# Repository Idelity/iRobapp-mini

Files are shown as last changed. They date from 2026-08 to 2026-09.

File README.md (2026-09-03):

# iRobapp-mini
AI＋ロボット＋アプリケーションの三位一体で生まれる卓上マスコット「iRobapp」の軽量版プロトタイプ

## 📂 ディレクトリ構成 (Directory Structure)

```text
iRobapp-mini/
├── 📁 cad/                       # ハードウェア設計データ
│   ├── 📁 scripts/               # FreeCAD用のPython生成スクリプト
│   └── 📁 stl/                   # 3Dプリンター出力用のSTLファイル
├── 📁 docs/                      # プロジェクトの解説ドキュメント
│   ├── assembly-guide.md         # iRobapp-miniハードウェアの組み立て手順書
│   ├── component-dimensions.md   # iRobapp-miniパーツ寸法表（FreeCAD設計基準）
│   ├── concept.md                # iRobapp-miniのコンセプトガイドについては下記を参照
│   ├── contributing.md           # 開発者向け：ローカル環境構築 ＆ 開発開始手順書
│   ├── development-log.md        # iRobapp-mini 開発日記 
│   ├── pinout-wiring-table.md    # iRobapp-mini ピンアサイン・配線表
│   └── system-specifications.md  # iRobapp-mini ソフトウェア・システム機能仕様書
├── 📁 firmware/                  # XIAO ESP32-S3用のコード
│   ├── 📁 main/                  # メインの制御ファームウェア
│   └── 📁 eye_assets/            # GC9A01液晶に表示する目の画像・アニメーションデータ
├── 📁 iOSApp/                    # Xcode
│   └── 📁 iRobappMiniController/ # iPhoneアプリのコード
├── .agents                       # GitHub Copilot用のエージェント指示書
├── .gitignore                    # 不要なファイル（FreeCADのバックアップ等）を除外する設定
└── README.md                     # プロジェクトの全体説明書
```
## 📄 iRobapp Documentation

- 🇯🇵 Japanese Concept Guide（日本語版コンセプトガイド）  
  https://github.com/Idelity/iRobapp/blob/main/docs/iRobapp-concept.md

- 🌍 English Concept Guide  
  https://github.com/Idelity/iRobapp/blob/main/docs/iRobapp-concept-en.md

> [!💡 お知らせ / Notice]
> 本家プロジェクト **[iRobapp](https://github.com/Idelity/iRobapp)** は、こちらを参照してください。
> 並行稼働プロジェクト **[Mocapy（モカピー）](https://github.com/Idelity/Mocapy)** は、こちらを参照してください。
>

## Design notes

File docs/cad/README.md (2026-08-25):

# 🤖 iRobapp-mini 卓上マスコット：4大コア部品の設計解説

本プロジェクト（iRobapp-mini）のハードウェア骨格は、FreeCADスクリプトから自動生成される**「4つの独立したコンポーネント」**が密接に連携することで成り立っています。それぞれの役割と設計思想は以下の通りです。

## 1. 001_Head_Face_Connector（頭部フェイスマウント）
* **【役割】**：丸型液晶（WAVESHARE 1.28inch LCD Module (19192)）をガタつきなく前面にホールドし、視線アニメーションを表現する「顔」の筐体です。底面で首のサーボモーター（SG90）に繋がる関節パーツとダイレクトに接続します。
* **【主要な設計寸法（スペック）】**：
  * **外形サイズ**：直径 44.0 mm（半径 22.0 mm）、奥行き 20.0 mm の非常にコンパクトなコップ型の円柱ベース。
  * **液晶ポケット**：直径 38.0 mm（半径 19.0 mm）、深さ 4.0 mm（市場の一般的なGC9A01モジュールがクリアランス込みでぴったり収まるサイズ）。
  * **配線エスケープ**：中央に 16.0 mm × 16.0 mm の角型貫通穴を配置。液晶背面からのFPCケーブルやジャンパ線をそのまま首の下へと逃がせる設計。
  * **マウントインターフェース**：首ジョイント（002）と結合するための、ピッチ 27.5 mm のM2ネジ用貫通穴（直径 2.2 mm）を2箇所に配置。
* **【設計のこだわり・評価ポイント】**：
  * **「耳」を兼ねたマウント設計**：頭部ベース（円柱）の底面に、幅 8.0 mm × 長さ 36.0 mm のフラットな「耳（拡張ブロック）」を一体化させて結合（`fuse`）している点が非常にスマートです。これにより、コンパクトな丸型ヘッドのデザインを維持したまま、サーボ固定用のネジ穴ピッチ（27.5mm）を綺麗に確保できています。
  * **3Dプリントを意識したブーリアン（くり抜き）順序**：液晶用ポケット、配線穴、M2ネジ穴をすべて1つのリストにまとめ、一括で結合してからメインボディをくり抜く（`cut`）シンプルなトポロジーを採用。FreeCAD上のトポロジーエラーが起きにくく、コードの実行速度も速い美しいスクリプト構成です。

## 2. 002_Neck_Joint_Mount（首ジョイントマウント）
* **【役割】**：頭部（001）と本体（003）を物理的に接続し、マスコットに上下（チルト）と左右（パン）の2軸（2自由度）の動きを与えるための中間関節パーツです。SG90サーボモーターを2個、直角に配置できる構造をスクリプトで自動生成します。
* **【主要な設計寸法（スペック）】**：
  * **頭部接続インターフェース**：幅 8.0 mm × 長さ 36.0 mm の上部プレート。001番の頭部底面と完全に一致するピッチ 27.5 mm のM2ネジ用貫通穴（直径 2.2 mm）を2箇所に配置。
  * **サーボポケット**：幅 23.0 mm × 厚み 12.8 mm（SG90サーボ本体の規格寸法にクリアランスを持たせた落とし込み穴）。
  * **サーボ固定マウント**：SG90のフランジ（耳）をネジ留めするための、ピッチ 27.5 mm のM2ネジ穴をY軸方向に配置。
* **【設計のこだわり・評価ポイント】**：
  * **完全なパラメータ同期（100%の嵌合整合性）**：001番のスクリプトで定義されていた `servo_screw_pitch = 27.5` という寸法が、この002番でも `head_screw_pitch = 27.5` として完全に引き継がれています。これにより、3Dプリント出力後に「ネジ穴が合わない」というトラブルが理論上発生しない完璧な連携設計になっています。
  * **空間効率の高いT字ブロック構造**：上部プレート、垂直壁、底部プレートを段階的に `fuse`（結合）し、そこにサーボポケットとネジ穴を一括で `cut`（くり抜き）するシンプルなトポロジーを採用。3Dプリンターで出力する際にも強度が保たれやすい肉厚（3mm）が確保されています。

## 3. 003_Body_Base_Case（本体ボトムケース）
* **【役割】**：マスコット全体の「体重」を支えるデスクトップ土台であり、首を左右に振る（パン）ためのSG90サーボモーター、メインマイコン（XIAO ESP32-S3）、スピーカー、電源スイッチ、および安全のためのヒューズホルダーをすべて内包する統合型エンクロージャーです。
* **【主要な設計寸法（スペック）】**：
  * **外形サイズ**：底面直径 70.0 mm（半径 35.0 mm）、上面直径 56.0 mm、高さ 40.0 mm の安定感のあるコーン形状。
  * **内蔵スペース**：肉厚 3.0 mm を均一に維持した広大なインナーポケット（下部からアクセス）。
  * **天面サーボマウント**：首振り用SG90サーボを落とし込む 13.4 mm × 23.4 mm のスリットと、002番と連携するピッチ 27.5 mm のM2ネジ穴（Z軸垂直貫通）を配置。
  * **背面インターフェース**：幅 12.0 mm × 高さ 19.0 mm の小型ロッカースイッチ用角穴、直径 12.0 mm のパネルマウント型ヒューズホルダー用丸穴、および **XIAO ESP32-S3用の給電・通信用USB-Cポート窓（幅 11.0 mm × 高さ 6.5 mm）** をまとめて配置。
* **【設計のこだわり・評価ポイント】**：
  * **一箇所に集約された外部インターフェース**：スイッチ、ヒューズ、USB-Cポートという「外から触る・挿す」必要のある要素をすべて背面（Y軸マイナス方向）の壁面へ機能的に集約しました。ロボットの正面側からは配線が一切見えないため、デスクトップマスコットとしてのノイズのない美観を保てます。
  * **コーン（円錐台）形状による低重心化**：頭部に液晶やサーボなどの重量物が集中する卓上ロボットにおいて、土台の底面を広く（直径70mm）、上部を狭くする設計は、ロボットが動いたときのブレや転倒を物理的に防ぐ非常に理にかなったアプローチです。

## 4. 004_Bottom_Lid_Battery_Holder（底蓋兼バッテリーホルダー）
* **【役割】**：003番の本体ボトムケースの底面にカチッとはめ込む蓋パーツです。内蔵するリチウムイオンポリマー（LiPo）バッテリーを物理的に挟み込んで固定し、ケース内部で部品が動いたり暴れたりするのを防ぐ「ホルダー」の機能も兼ね備えています。
* **【主要な設計寸法（スペック）】**：
  * **外形サイズ**：直径 約 63.2 mm（半径 31.6 mm）、ベース厚み 2.0 mm の薄型円盤構造。003番の底面内径（64.0 mm）に対して、3Dプリンターでの出力収縮や嵌め合いを考慮した **片側 0.2 mm（全体で 0.4 mm）のクリアランス** をあらかじめ自動計算で適用。
  * **バッテリーホルダー部**：幅 26.0 mm、厚み 8.0 mm までの小型LiPoバッテリー（500mAh〜800mAhクラス）をぴったりホールドできる、長さ 30.0 mm × 厚み 2.0 mm の一対の垂直固定リブ（壁）を中央に配置。
* **【設計のこだわり・評価ポイント】**：
  * **3Dプリント一発出力に適した「積層構造」**：オーバーハング（空中に浮く部分）が一切ない設計になっており、3Dプリンターで出力する際に「サポート材」を全く必要としません。底面を下にして置くだけで非常に綺麗かつスピーディにプリントが可能です。
  * **メンテナンス性と安全性の両立**：バッテリーを両サイドから適度な摩擦で挟み込む「クリップ構造」にしているため、ネジ留めが不要です。バッテリーの交換や、内部の配線メンテナンスを行いたい時は、底蓋を外すだけで簡単にアクセスできる親切な設計になっています。

---

### 💡 設計思想の評価（パラメトリック・モジュール化）
FreeCAD上でパーツごとにスクリプトを分離したことで、**「頭（液晶表示・配線窓） ↔ 首（サーボ結合・M2ピッチ27.5mm） ↔ 体（サーボ格納・マイコン固定） ↔ 底蓋（バッテリー保持）」**という一連の物理的・機能的リンクが綺麗にカプセル化されています。
これにより、「液晶のサイズを変えたい時は001だけ」「サーボを別のものに変えたい時は002と003だけ」「バッテリーを大容量化したい時は004だけ」というように、他の部品に影響を与えずパラメトリックに独立してカスタマイズできる点が非常に優れた設計思想です。

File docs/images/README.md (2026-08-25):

# iRobapp-mini 画像・図面アセット管理

このフォルダには、`iRobapp-mini` の設計、回路、ドキュメントで使用する画像やデザインの元データを格納しています。

---

## 🔌 回路結線図の更新ルール 🎵

回路図（ピンアサインや配線）に変更があった場合は、以下の手順でデータを更新してください！
画像ファイル名（`.png`）とフリーボードから出力したファイル名（`.pdf`）は、常に同じ名称（`circuit-diagram`）で統一して管理しています。

### 🔄 更新の 3 ステップ

1. **Mac のフリーボードで修正する**
   * 同フォルダにある元データ `circuit-diagram.pdf` を Mac で開き、フリードーにpdfの内容を貼り付けてピンアサインや配線をパパッと修正します。
2. **画像（PNG）として書き出す**
   * 修正が終わったら、フリーボードから「PDFとして書き出し」→「PNG形式（ファイル名：`circuit-diagram.png`）」として Mac に保存します。
3. **GitHub へ上書きアップロード！**
   * GitHub のこのフォルダ（`docs/images/`）を開き、新しく作った `circuit-diagram.png` と `circuit-diagram.pdf` の両方を**同じファイル名のままドラッグ＆ドロップ**して上書きコミットします。

> 💡 **ここがポイント！**
> ファイル名が同じであれば、ドキュメント（`ピンアサイン・配線表.md`）側のリンクを書き直さなくても、自動的に最新のきれいな回路図にパッと切り替わります！

---

## 📂 ファイル一覧

| ファイル名 | 形式 | 役割 |
| :--- | :--- | :--- |
| **`circuit-diagram.png`** | 画像 (PNG) | 各種ドキュメント（Markdown）表示用の配線図 |
| **`circuit-diagram.pdf`** | Mac編集データ | 再編集・修正を行うためのフリーボード元データ（バックアップ） |

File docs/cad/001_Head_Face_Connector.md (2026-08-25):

## 1. 001_Head_Face_Connector（頭部フェイスマウント）

* **【役割】**：丸型液晶（Waveshare 1.28inch LCD Module）をガタつきなく前面にホールドして視線アニメーションを表現すると同時に、内部にオーディオアンプとスピーカーを格納する、iRobapp-miniの「顔と音」を司る中空筐体です。底面で首のサーボモーター（SG90）に繋がる関節パーツとダイレクトに接続します。

### 📐 主要な設計寸法（スペック）
* **外形サイズ**：直径 44.0 mm（半径 22.0 mm）、奥行き 20.0 mm の非常にコンパクトでクリーンな円柱ベース。
* **液晶ポケット**：直径 38.0 mm（半径 19.0 mm）、深さ 4.0 mm（WAVESHARE 1.28inch LCD Module (19192) がクリアランス込みでぴったり収まるサイズ）。
* **【新設】コネクタ逃げスリット**：液晶ポケットの下部（Y軸マイナス方向）に、基板裏の突起部品を逃がすための**幅 20.0 mm × 縦 5.0 mm × 深さ 4.0 mm のスクエアスリット**を配置。
* **配線エスケープ**：中央に **直径 22.0 mm（半径 11.0 mm）のクリーンな完全貫通丸穴（センターVoid）** を配置。液晶背面からの配線や各パーツのジャンパ線をそのまま首の下へと最短距離で逃がせる設計。
* **マウントインターフェース**：首ジョイント（002）と結合するための、ピッチ 27.5 mm のM2ネジ用穴（半径 1.1 mm / 深さ 5.0 mm の浅型仕様）を2箇所に配置。外形の円柱の厚み内に美しく内蔵。

### ⚙️ 設計のこだわり・評価ポイント
* **現物合わせによる「コネクタ逃げ」の精密設計**：
  秋葉原で調達した Waveshare 19192 の実物基板にある下部の出っ張りに合わせ、干渉を避ける専用の逃げスリット（`conn_escape`）を新設。これにより液晶が浮かずに100%奥までフラットにはめ込めるようになりました。
* **限られた空間への音響システムの高密度実装**：
  外径44mmという極小のヘッドサイズを維持したまま、内部のデッドスペース（床面左側および右側側面）を有効活用し、アンプ固定リブとWスピーカーリブをブーリアン演算で一体化。ガタつきのない強固な内装構造を実現しています。
* **3Dプリントを意識した高精度な一体化トポロジー**：
  すべてのくり抜き用カッター（液晶ポケット、コネクタスリット、センターVoid、ネジ穴）を1つのオブジェクトに結合して一発で `cut` した後、追加リブ群をダイレクトに `fuse` する美しいスクリプト構成を採用。FreeCAD上でのトポロジーエラーを完全に排除しています。

### 📺 内蔵部品リスト

頭部ユニットは「視覚（顔）」と「聴覚（音声出力）」の表現をワンパッケージに凝縮し、首パーツへの負担を減らすため効率的に肉抜きされた高密度構造をしています。

* **WAVESHARE 1.28inch LCD Module (19192) × 1個**
  * **【配置】**：頭部前面に設計されたフロントポケットに、下部コネクタをスリットに合わせる形でガタつきなく綺麗にはめ込まれます。
  * **【役割】**：マスコットの「顔（液晶画面）」となり、駆動チップ（GC9A01）を介してファームウェアから描画される豊かな表情やアニメーションを映し出します。
* **SparkFun I2S Audio Breakout (MAX98357A搭載) × 1個**
  * **【配置】**：頭部内部の左側奥の床面（floor_tの上）に新設された、**高さ 10.0 mm / 厚み 2.0 mm の専用アンプ挟み込みリブ（2基）**の間にカチッと固定されます。
  * **【役割】**：ESP32-S3から送られてくるデジタル音声データを高品質なアナログ音声信号に変換・増幅し、Gemma-2Bの声をリアルタイムに響かせる脳の役割を果たします。
* **ブレッドボード用ダイナミックスピーカー (MS128-12R) × 1個**
  * **【配置】**：頭部内部の右側側面に配置された、**幅 5.0 mm / 縦 15.0 mm の15mm幅ワイド削り切りWリブ**（Z=12.0mmとZ=4.5mmの2基）の溝にスライドしてホールドされます。
  * **【役割】**：I2Sアンプからの信号を受け、圧縮なしの音声ストリーミングデータをクリアな音圧で卓上に届けます。
* **液晶および音響用 配線ケーブル一式**
  * **【ルート】**：液晶・アンプ・スピーカーから伸びるすべてのジャンパ線は、中央の**直径 22.0 mm の完全貫通丸穴**をストンと通り抜け、外から一切見えない状態でそのまま首（002）の中空スペースへと引き込まれます。

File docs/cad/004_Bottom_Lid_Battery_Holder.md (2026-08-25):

 ## 4. 004_Bottom_Lid_Battery_Holder（底蓋兼バッテリーホルダー）

* **【役割】**：iRobapp-mini の最底面を閉じる蓋（リッド）であり、同時に電源系の生命線である「リチウムイオンポリマー電池」「保護ヒューズ」「電源メインスイッチ」をワンパッケージで確実にホールドする電源マネジメントベースです。

### 📐 主要な設計寸法（スペック）
* **全体サイズ**：直径 約63.2 mm（半径 31.6 mm / 本体底面 70.0 mm に対し、壁厚 3.0 mm とクリアランス 0.4 mm を引いたジャストサイズ）。厚み 2.0 mm の円盤ベース。
* **バッテリーホルダー仕様**：
  * 千石電商で調達したリポ電池（DTP502535 / 3.7V 400mAh）に最適化。クリアランスを加味した**内寸幅 26.0 mm、リブ高さ 8.0 mm、リブ厚み 2.0 mm、長さ 30.0 mm** の対向Wリブ構造。
* **ヒューズポケット仕様**：
  * 秋月電子で調達したリセッタブルヒューズ（MF-R090）に最適化。**内幅 12.2 mm × 内厚 3.6 mm × 高さ 10.0 mm**（壁厚 1.5 mm）の専用ポケットを Y = 16.0 mm の位置に配置。
* **スイッチホルダー ＆ 操作用スリット仕様**：
  * 秋月電子で調達したスライドスイッチ（SS-12D00G）に最適化。スイッチ本体を囲う**内幅 9.1 mm × 内厚 4.0 mm × 高さ 7.0 mm**（壁厚 1.5 mm）の筒状ホールド壁を Y = -22.0 mm の位置に設置。
  * **【修正点】つまみ用貫通スリット**：底面の外側から爪でスイッチを直接オン/オフ操作できるよう、ホルダー中心の真底に **幅 4.5 mm × 厚み 2.5 mm の完全貫通スリット穴** をぶち抜いた構造。

### ⚙️ 設計のこだわり・評価ポイント
* **秋葉原調達パーツのリアル寸法に100%アジャスト**：
  データシート上の数値だけでなく、実際のパーツのリード線の出っ張りやケースの歪みを考慮したクリアランス（電池幅+1.0mm、スイッチ幅+約0.5mm等）が最初から計算に組み込まれており、プリント後の微調整が不要な一発フィット仕様になっています。
* **頑丈かつ合理的なブーリアン処理（先に合体、後から一発穴あけ）**：
  ベースの円盤に対してバッテリーリブ、ヒューズポケット、スイッチホールド壁をすべて先に結合（`fuse`）して強固な1つのソリッドにしてから、最後につまみ用の貫通スリット（`final_slot`）を `cut` で一気貫通させるスクリプト構成を採用。トポロジーの破綻を防ぎつつ、スイッチ裏の底が完璧に抜けた美しい構造を実現しています。

### 📺 内蔵・搭載部品リスト

底蓋ユニットは、ロボット全体の低重心化に貢献する電源コンポーネントの集積地です。

* **リチウムイオンポリマー電池 (DTP502535) × 1本**
  * **【配置】**：中央の幅 26.0 mm のWリブホルダーの間に格納されます。
  * **【役割】**：iRobapp-miniの動力源（3.7V 400mAh）。卓上でのコードレス駆動を実現します。
* **リセッタブルヒューズ 0.9A (MF-R090) × 1個**
  * **【配置】**：Y軸奥側の専用ヒューズポケットに縦向きに差し込まれます。
  * **【役割】**：万が一の短絡（ショート）や過電流（1.8Aトリップ）が発生した際、自動で回路を遮断して大切なESP32やリポ電池を発熱・発火トラブルから守る安全弁です。
* **スライドスイッチ (SS-12D00G) × 1個**
  * **【配置】**：Y軸手前側のホールド壁の中に、つまみを下に向けてパチンとはめ込まれます。
  * **【役割】**：主電源のON/OFF切り替え。底面の穴からいつでも安全にシャットダウンが可能です。

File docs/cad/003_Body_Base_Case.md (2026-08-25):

## 3. 003_Body_Base_Case（本体ボトムケース）

* **【役割】**：マスコット全体の「体重」を支えるデスクトップ土台であり、首を左右に振る（パン）ためのSG90サーボモーター、メインマイコン（XIAO ESP32-S3）、神経系と駆動系をスマートに包み込む中核パーツです。

### 📐 主要な設計寸法（スペック）
* **外形サイズ**：底面直径 70.0 mm（半径 35.0 mm）、上面直径 56.0 mm、高さ 40.0 mm の安定感のあるコーン形状。
* **天面インターフェース**：
  * 首振り用サーボ（SG90）落とし込み穴（横 23.0 mm × 厚み 12.5 mm）およびピッチ 27.5 mm のM2ネジ穴（直径 2.2 mm）。
  * 001の頭部丸型液晶から降りてくる太いジャンパ線一束をスムーズに胴体内に引き込むための**独立した配線専用大穴（直径 10.0 mm / 半径 5.0 mm）**。
* **背面インターフェース**：
  * **下部**：XIAO ESP32S3 の電源・書き込み用 USB-Cポートに外から直接アクセスするための専用窓（幅 11.5 mm × 高さ 7.0 mm）。
  * **上部**：尻尾を動かすためのSG90サーボ窓（横 23.0 mm × 厚み 12.5 mm）およびピッチ 27.5 mm のM2ネジ用穴。

### ⚙️ 設計のこだわり・評価ポイント
* **一箇所に集約された外部インターフェース**：
  スイッチ、ヒューズ、USB-Cポートという「外から触る・挿す」必要のある要素をすべて背面（Y軸マイナス方向）の壁面へ機能的に集約しました。ロボットの正面側からは配線が一切見えないため、デスクトップマスコットとしてのノイズのない美観を保てます。
* **コーン（円錐台）形状による低重心化**：
  頭部に液晶やサーボなどの重量物が集中する卓上ロボットにおいて、土台の底面を広く（直径70mm）、上部を狭くする設計は、ロボットが動いたときのブレや転倒を物理的に防ぐ非常に理にかなったアプローチです。

### 🪵 内蔵部品リスト

本体ボトムケースは、マスコット全体の「体重」を支える低重心なコーン型（円錐台）のエンクロージャーです。外壁3mmを残して下側から大きくくり抜かれた「インナーポケット（ドーム空間）」の中に、すべての基板、バッテリー配線、および2つの可動サーボを立体的に完全内蔵します。

* **首振り（左右パン）駆動用サーボモーター（SG90） × 1個**
  * **【配置】**：土台の「最天面（天井）」にある 13.4 mm × 23.4 mm の長方形スリットに上から差し込まれ、M2ネジ2箇所で固定されます。
  * **【役割】**：白い回転軸だけを天面から上に飛び出させ、首ジョイント（002）の下面ホーンと噛み合って頭部全体を左右にきょろきょろと動かします。
* **尻尾フリフリ駆動用サーボモーター（SG90） × 1個**
  * **【配置】**：土台背面の最上部（Z=24.0mm〜36.4mm）にある 23.0 mm × 12.4 mm の専用窓に横向きに寝かせて埋め込まれ、左右2箇所のM2ネジで固定されます。
  * **【役割】**：回転軸を真後ろ（外側）へ飛び出させ、取り付けられた可愛い尻尾パーツをフリフリと左右にスイングさせます。首振りサーボの下に配置することで、内部干渉を完璧に回避しています。
* **メインマイコン（XIAO ESP32-S3） × 1個**
  * **【配置】**：ドーム内部の左後ろ側、壁面に開けられた幅 11.0 mm × 高さ 6.5 mm の「USB-Cアクセス窓」の真裏に両面テープ等で固定されます。
  * **【役割】**：ロボットの「電子頭脳」です。外部から挿し込まれたType-Cケーブルを介して、内蔵バッテリーへの安全な充電、および液晶やサーボを制御するファームウェアの書き込みを行います。

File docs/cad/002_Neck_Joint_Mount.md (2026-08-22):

## 2. 002_Neck_Joint_Mount（首ジョイントマウント）

* **【役割】**：頭部（001）と本体（003）を物理的に接続し、マスコットに愛らしい感情表現を与える中間関節パーツです。すべての厚みが3mmに統一された、前方が完全開口した「コの字型フレーム構造」をスクリプトで自動生成します。

### 📐 主要な設計寸法（スペック）
* **外形サイズ**：幅 8.0 mm × 奥行き 36.0 mm × 高さ 33.0 mm（内寸：高さ 27.0 mm / 奥行き 33.0 mm、全肉厚 3.0 mm）。
* **頭部接続インターフェース**：36.0 mm × 8.0 mm の天面プレート。001番の頭部底面と完全に一致するピッチ 27.5 mm のM2ネジ用貫通穴（2箇所）を配置。
* **土台接続インターフェース**：36.0 mm × 8.0 mm の底面プレート。裏側にSG90付属の一文字プラスチックホーンが収まる深さ 1.5 mm の溝を配置。結合用として「両脇の固定ミニビス穴（2箇所）」に加え、サーボの回転軸と直結するための「中央メイン軸ネジ用貫通穴（1箇所）」の計3穴を垂直に配置。

### ⚙️ 設計のこだわり・評価ポイント
* **組み立て性と工具アクセスを極めた「コの字」デザイン**：
  前方を完全にオープンにしたブラケット形状にすることで、3Dプリント後の実機組み立て時に、横や前方から長いドライバーを差し込んで底面のサーボ中心ネジをダイレクトに締め付けることができます。「作ってみたら工具が入らずネジが締められない」という3Dガジェット開発特有の罠を、形状の工夫で100%解決した非常にスマートな設計です。
* **配線の自由度と強度の両立**：
  左右非対称な壁ではなく、背面側にのみ強固な縦壁（30.0 mm × 8.0 mm）を配置するバックボーン構造を採用。頭部から降りてくる液晶のコード類を、コの字の中空空間からガサッとまとめて下部へ逃がせるため、断線リスクを最小限に抑えています。

### 🦴 接続・中継部品リスト

首ジョイントは、頭部（001）と体（003）を物理的につなぎ、下のサーボの回転をダイレクトに頭へ伝える、厚み3mm・幅8mmの超スリムな「コの字型中継フレーム」です。自身の中にパーツを閉じ込めるのではなく、2つの部品を繋ぐための重要なマウント構造を内蔵しています。

* **頭部（001）接続インターフェース × 1面**
  * **【配置】**：コの字の「天面（上の板）」に配置。ピッチ 27.5 mm のM2ネジ用穴が2箇所貫通しています。
  * **【役割】**：001の頭部パーツの底面と重ね合わせ、M2ネジでがっちりと一体化固定します。
* **パン（左右）駆動用 サーボホーン（一文字型） × 1個**
  * **【配置】**：コの字の「下面（底の板）」の裏側に設計された、幅 5.0 mm × 長さ 16.0 mm × 深さ 1.5 mm の専用溝（`horn_pocket`）にパチンとはめ込まれます。
  * **【役割】**：両脇の2穴をミニビスで首の樹脂に固定し、中央のメイン軸穴からドライバーを挿して土台（003）のサーボ軸と直結。これにより、土台のサーボが回ると首パーツごと頭が左右にきょろきょろ回ります。
* **頭部配線の中継・たるみ（エスケープ）スペース**
  * **【配置】**：コの字の内側にある、高さ 27.0 mm の中空空間です。
  * **【役割】**：頭部（001）の丸穴から降りてきた液晶ケーブルをこの空間に通し、あえて数ミリの「たるみ（余裕）」を持たせて収納します。このゆとりがあるおかげで、首が左右に激しく回っても配線が引っ張られて千切れるのを完璧に防ぎます。

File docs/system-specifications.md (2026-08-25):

# 📱 iRobapp-mini ソフトウェア・システム機能仕様書 

本ドキュメントは、iPhone（コントローラー）とiRobapp-mini（エッジロボット）間の協調動作、通信プロトコル、および各機能の実装要件を定義するマスター仕様書である。

---

## ⚙️ 1. システムアーキテクチャ & 通信
*   **筐体/デバイス**: 
    *   **コントローラー**: iPhone (iOSアプリ)
    *   **ロボット**: XIAO ESP32-S3
*   **通信方法**: Bluetooth Low Energy (BLE) 通信
    *   iPhoneをマスター（セントラル）、ESP32-S3をスレーブ（ペリフェラル）として構成。
    *   音声データは、遅延を最小化するためパケット単位での「リアルタイム音声ストリーミング方式」を採用する。

---

## 🧠 2. 統合機能仕様

### 🎙️ A. おしゃべり機能（音声ストリーミング）
ハンダ付けを全廃したハードウェア構成で低遅延な対話を実現するため、以下のパイプラインで音声を処理する。

1.  **音声認識 (STT)**: iPhone側でユーザーの発話を音声認識し、テキスト化。
2.  **思考 (AI)**: テキストを後述のAIエンジン（CloudまたはLocal）に投入し、返答テキストを生成。
3.  **音声合成 (TTS)**: 返答テキストをiPhone側でリアルタイムに音声データに合成。
4.  **ストリーミング転送**: iPhone側で軽量圧縮した音声を細切れのパケットデータとして、BLE経由で順次ESP32-S3へストリーミング送信。
5.  **リアルタイム再生**: ESP32-S3は受信したバッファを順次解凍し、I2S経由でMAX98357Aアンプを叩き、スピーカーから即座に再生。

### 🤖 B. AI連携機能（マルチLLM/SLMエンジン）
ユーザーの利用環境やコストの好みに合わせて、iOSアプリの設定画面から2つのモードを切り替え可能とする。

*   **有料版 (Cloud LLM)**: 
    *   **エンジン**: OpenAI ChatGPT API
    *   **要件**: アプリの設定画面で、ユーザー自身が契約した「OpenAI APIキー」を入力して通信を行う。
*   **無料版 (Local SLM)**: 
    *   **エンジン**: Gemma 2B (Google) ※デバイスローカル動作
    *   **要件**: iPhoneのオンデバイスAIランタイムを利用し、完全オフラインで高速な推論を実行する。
    *   *備考*: Microsoft Phi-3の対応は将来的な拡張予定（バックログ）とする。

### ⚙️ C. 首振り機能（パンサーボ制御）
1.  **トリガー動作**: ユーザーがiPhoneに話しかけたタイミングで、ロボットはiPhone（ユーザー）がいる方向を向くように体を回転させる。
2.  **自律動作（ランダム探索）**: アプリの動作モードに応じて、タイマーおよび乱数（ランダム値）に基づいた時間間隔で、不定期に首をきょろきょろと左右に回転させ、生命感を演出する。

### ⚙️ D. 尻尾振り機能（テールサーボ制御）
1.  **トリガー動作**: ユーザーがiPhoneに話しかけたタイミングで、尻尾をキュキュッと「2回」小気味よく振る。
2.  **自律動作（ゴキゲン演出）**: 首振り機能と同様に、モードに応じた乱数値ベースの間隔で、自律的に尻尾をフリフリと動かす。

### 📺 E. 瞬き・視線リアルタイム演算機能（液晶グラフィック制御）
LovyanGFXの強力な幾何学図形描画機能を利用し、WAVESHARE 1.28inch LCD Module (19192)［制御IC: GC9A01］にデジタルな瞳をリアルタイム合成する。

1.  **瞬き（まばたき）**: 3パターンの時間間隔を乱数で切り替えながら、自然な瞬きを繰り返す。
2.  **スリープモード**: 長時間ユーザーからの操作や発話がない場合、スリープ状態に移行して瞳を完全に閉じ、消費電力を抑える。
3.  **視線リアルタイム追従（将来拡張用）**: 
    *   iPhone側から送られてくる角度や各種座標数値データをESP32-S3がリアルタイムに受信。
    *   LovyanGFXの関数（`fillCircle` 等）を使い、**黒目の円の座標（Y軸）をリアルタイム計算でスムーズに滑らかに動かす**表現を実装する。
    *   *備考*: iPhoneとロボットの物理的な位置関係による完全自動の視線連動は将来のアップデート予定とする。

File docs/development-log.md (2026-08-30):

# iRobapp-mini 開発日記 (Development Log)

`iRobapp-mini` の開発プロセス、試行錯誤、学んだことを記録していくドキュメントです。

---

## 2026年8月22日（土）：プロジェクト始動

iRobapp-miniの構想を固め、4大コア部品のコード化と個別ドキュメント化を一日で一気にやり遂げた、圧倒的密度の開発初日。

* **やったこと**
  * iRobapp-mini の全体コンセプトを整理
  * GitHubにリモートリポジトリを作成し、ファーストコミットを完了
  * **FreeCADを用いたパーツ設計の自動化と4大コア部品の一挙コード化**
    * 当初はFreeCADのGUI上で「スケッチを描いて、押し出して（膨らませて）…」という面倒な手動手順をジェミーに聞きながら学習していた。
    * 途中で**「Pythonスクリプトを使えばコードで3Dモデルを作れる」**と知る。
    * そこから方針を転換し、ジェミーにベースとなるPythonコードを考えてもらい、自分がそれをFreeCADに流して画面で確認、修正点をジェミーに伝えてブラッシュアップしていくという共同開発スタイルを確立。
    * この手法により開発が爆速化し、初日のうちに以下の4つのコア部品をすべてスクリプト化することに成功した。
      * `001_Head_Face_Connector.py`（頭部と顔のコネクタ）
      * `002_Neck_Joint_Mount.py`（首のジョイントマウント）
      * `003_Body_Base_Case.py`（胴体のベースケース）
      * `004_Bottom_Lid_Battery_Holder.py`（底蓋兼バッテリーホルダー）
  * **設計ドキュメント類の完全整備（`doc/cad/` 内の拡充）**
    * 各パーツのコード化と並行して、それぞれの設計意図をまとめた個別Markdown（`001`〜`004`の.md）を作成。
    * さらに、これらを体系的にまとめた解説書（`doc/cad/README.md`：「iRobapp-mini 卓上マスコット：4大コア部品の設計解説」）も同時に執筆・追加した。
  * **電気回路・ピンアサインの仕様策定**
    * ドキュメント `統合ピンアサイン・配線表.md` を新規追加。
    * マイコンと各コンポーネント（サーボモーターや各種センサー等）をどう繋ぐか、ピン配置と配線計画を明確に定義した。

<br>

> 💡 **相棒の紹介**
> GeminiはGoogleが開発したAIモデルの名前でジェミニと読みます。
> 私は開発を一緒に並走する「AIの相棒」としてジェミニを選びました。
> この文章に出てくるジェミーとは、これの事です。

---

## 2026年8月23日（日）：CAD修正、ドキュメント大移動、そしてソフト・ファームウェア開発・iOS開発への全面突入

外装のブラッシュアップから始まり、リポジトリ構成の再編、組み込み、iOS、そしてAIアーキテクチャの変更まで、プロジェクトが全方位に爆発的進化を遂げた日。

* **やったこと**
  * **ハードウェア設計の継続と手順書作成**
    * `001`〜`004` のスクリプトおよびドキュメント（.md）を修正・最適化。
    * 組み立て方法をまとめた `assembly.md（iRobapp-mini ハードウェア組み立て手順書）` を新規作成。
  * **GitHub運用とドキュメント配置の試行錯誤（デリート＆インサート）**
    * 配線表のファイルを修正し、名前を `ピンアサイン・配線表.md` に変更。
    * 保存場所を `docs/cad` から `docs/` 直下へ移動させる際、GitHubの操作（Gitの移動履歴管理）に苦戦。最終的に「元ファイルを削除して新場所に作り直す（デリート＆インサート）」という力技で乗り切る。
  * **ファームウェア（Arduino）開発のスタートと `.gitignore` との対面**
    * `ソフトウェア・システム機能仕様書.md` を作成し、仕様を定義。
    * マイコン（ESP32-S3）用の実装コード `main.ino` を作成し、Arduinoでの開発が本格始動。
    * ビルド時の生成物などをGit管理から外すため、初めて `.gitignore` の設定を強く意識する必要性と直面した。
  * **iOS（Xcode）アプリの爆速開発と実機確認**
    * iPhone側の制御アプリ開発に着手。環境構築のみならず、主要コンポーネントを一気に実装した。
      * `iRobappMiniController.xcodeproj`（プロジェクト基盤）
      * `BLEManager.swift`（Bluetooth通信制御）
      * `ContentView.swift` / `iRobappMiniControllerApp.swift`（UI画面表示）
      * `VoicePipelineManager.swift`（音声ストリーミング等のパイプライン）
      * `GemmaAIManager.swift`（ローカルLLM連携管理）
    * 恐ろしいスピードで実装が進み、同日のうちにコンパイルを通し、iPhone実機での画面表示確認まで完了。
    * 将来、自分以外の開発者がプロジェクトに参加したときのために、スムーズに着手できるように `開発者の方へ.md` を作成。
  * **AI（ローカルLLM）と音声通信アーキテクチャの重大な決断**
    * 当初は「Phi-3」の搭載を想定していたが、卓上マスコットのリソースとしては大きすぎるという問題に直面。
    * より軽量で高効率な **「Gemma-2B」** へと切り替える意思決定を行った。
    * 同時に、音声データを一度圧縮してから転送する当初の流れを撤廃。レスポンス速度を最優先し、**音声のストリーミング再生**へと仕様を変更。上記の `VoicePipelineManager.swift` や `GemmaAIManager.swift` の設計に即座に反映した。

---

## 2026年8月24日（月）：秋葉原買い出しと実物パーツ寸法のCADフィードバック、回路結線図の作成

バーチャルな設計から、リアルな部品調達と現物合わせの最適化、正確なピンアサインの可視化へとシフトした日。

* **やったこと**
  *  * **秋葉原での部品調達（リアルハック）**
    * 秋月電子通商と千石電商を巡り、メインマイコン（XIAO ESP32S3）、1.28インチ丸型LCD、I2Sオーディオアンプ（MAX98357A）、リポ電池（400mAh）などを調達。
    * **試行錯誤（パーツの選定ミスと即時対応）**
      * 当初購入した「電圧スピーカー（圧電サウンダー）」では、今回の目的である音声ストリーミング（人の声の再生）に対応できないことが判明し、不採用へ。
      * 音声再生の要として、同時に購入していた「I2Sアンプ＋ダイナミックスピーカー」の構成をメインとして採用することを決定。
  * **現物に基づくパーツ寸法表の作成**
    * 手に入れた実物の電子部品・電池のサイズを精密に測定し、パーツ寸法表として落とし込んだ。
  * **実物サイズに合わせたPythonコードの修正**
    * 寸法表のリアルな数値を元に、`001_Head_Face_Connector.py`、`003_Body_Base_Case.py`、`004_Bottom_Lid_Battery_Holder.py` のコードを修正。
    * 電池や基板が物理的にきっちり収まるように外装マウントの設計を最適化した。
  * **グラフィカルな回路結線図の作成（大仕事）**
    * 調達したパーツ一式（マイコン、LCD、I2Sアンプ、スピーカー、リポバッテリー、スイッチ、ヒューズ、サーボモーター×2）を網羅した詳細な配線図をグラフィカルに作成。
    * 電源ライン（VCC/GND）や各通信ピン（I2S、SPI等）の接続先を視覚的に完全に見える化し、ハンダ付けや実装のミスのない基盤を固めた。

---

## 2026年8月25日（火）：ドキュメンテーションの完全整備、ピンマップの謎解き、そして実機配線フェーズ突入！

これまでの激動の開発履歴を整理し、秋葉原調達パーツのリアル寸法および内部ピン相性を100%反映させた、プロジェクトの「大クリーンアップ＆基礎工事完了」の日。

* **やったこと**
  * **過去3日間の日記データ大救出とお引っ越し**
    * 画面操作の過程で別リポジトリに誤って複数コミットされていた過去3日分（8/22〜8/24）の濃密な開発ログを発見。中身を無傷で本命の `iRobapp-mini` リポジトリへお引っ越しさせ、開発日記（`development-log.md`）の本格運用を開始。
  * **実物パーツ寸法に基づくCAD仕様書（3枚）の完全同期**
    * 昨日秋葉原（秋月・千石）で調達したリアルなコンポーネントに基づき、`001_Head_Face_Connector.md`、`003_Body_Base_Case.md`、`004_Bottom_Lid_Battery_Holder.md` の寸法数値を最新のPythonコードと100%一致するように改訂。
    * 特に、アンプとスピーカーを003（胴体）から001（頭部）へ大移動させた昨日の設計変更に合わせ、ハードウェア組み立て手順書（`assembly-guide.md`）のステップ1（頭部内装閉鎖）およびステップ4（ボトム蓋格納）を現実のビルドフローへ完全アジャストした。
  * **回路結線図の二重バックアップ体制と運用ルールの構築**
    * Macのフリーボードで作成した詳細な回路図から、Markdown表示用の「PNG画像」と、今後のピンアサイン修正に備えたベクター元データとしての「PDF形式」を書き出し。
    * `docs/images/README.md` を新設し、「フリーボードを修正して同名で上書きすればドキュメント側も自動更新される」という効率的なアセット管理手順（3ステップ 🎵）を定義した。
  * **XIAO ESP32-S3「神のピンマップ」同期と相性問題の完全クリア**
    * 公式のピンマップを調査し、D6（GPIO43）とD7（GPIO44）が内部でワープしている通信ピンの特殊仕様を特定。
    * 起動時に一瞬ノイズパルスが走りやすい特性を考慮し、暴れては困るサーボやアンプを避け、影響の出ない「液晶のリセット・CSピン」へ割り当てている現在の結線が「実機が最も安定して動く100点満点のプロ設計」であることを証明・配線表にリファレンスマップとして追記した。
  * **リポジトリのファイル名リファクタリング**
    * 将来のポートフォリオ展開や海外エンジニアへの視認性（アクセシビリティ）を考慮し、`docs/` 内の全Markdownファイルの名前を英語の `kebab-case`（`system-specifications.md` や `pinout-wiring-table.md` など）へ美しく一括リネーム。履歴（履歴）を引き継いだままクリーンアップ完了。
  * **実機パーツの物理配線およびテストファームウェアの準備（最終目標）**
    * 確定したマスターピンアサインに基づき、ブレッドボード上での物理的な回路結線作業に着手。
    * ピン定義と各コンポーネントの初期化テストを行うファームウェアの骨組み（`main.ino` の土台）を準備した。

---

## 2026年8月26日（水）：音声データ直撃パイプライン開通！数々のノイズの壁が立ちはだかるもベースライン確立フェーズ完了！

昨日の物理配線完了を受け、iPhoneアプリ（Swift）とロボット（ESP32-S3 / Arduino）の間で、音声認識（STT）➔ ローカルAI（Gemma 2B）➔ 音声ストリーミング（TTS）を1本の線で繋ぐ「三位一体の通信パイプライン」の実装と、実機オーディオ特有の物理現象に挑んだ激闘の日。

* **やったこと**
  * **Swift（iOS）➔ BLE ➔ ESP32-S3 音声パケット直撃ラインの開通**
    * `VoicePipelineManager.swift` と `BLEManager.swift` をリファクタリングし、iOSの音声合成エンジン（`AVSpeechSynthesizer`）が生成するバッファを細切れ（180バイトパケット）にして高速送信する仕組みを実装。
    * マイコン側の音声用特性（`CHARACTERISTIC_VOICE_UUID`）に、iPhoneから応答を待たずに爆速で流し込める `.withoutResponse`（NR属性）をマイコン側設定（`PROPERTY_WRITE_NR`）に追加。iOSの自動送信ブロックを解除し、データ開通に成功。
  * **型解釈・エンディアン・ポインタの謎解きとコンパイルエラーの撲滅**
    * iOSの生成する `Float32` データを、複雑な `AVAudioConverter` のブラックボックスに頼らず、数式だけで直接 `Int16` にキャスト＆ダウンサンプリングする「超純粋直撃キャストコード」を開発。
    * SwiftのUnsafeポインタの挙動（メモリアドレス混入）によるデジタル砂嵐を防ぐため、1サンプルずつ明確にマイコン側の脳みそと噛み合う「リトルエンディアン（`littleEndian`）」へ強制固定してData化する処理を確立。
  * **端数パケットによる無音化バグ（I2Sデッドロック）の解消**
    * 複雑化していたFreeRTOSのマルチコアタスク（Core 1分離キュー）において、BLEの高速割り込みと再生クロックが衝突し、180バイト未満の端数パケットが届いた瞬間にI2Sドライバーがパニックを起こして完全無音化するバグを発見。
    * 複雑なキュー処理をあえて全廃し、起動音（サイン波計算）と同じ最もピュアな「1chモノラル・I2S直撃ルート」へ原点回帰。端数パケットのサイズに左右されず、スピーカーから確実に音が鳴る状態まで復活（ベースラインのセーブ）。
  * **アンプ（MAX98357A）と小型スピーカーの電気的特性（ミスマッチ）の特定**
    * 計算上の最大値（等倍：32767）でデータを送ると、強力なアンプ（最大3.2W）のパワーが小型スピーカー（MS128-12R）の物理的限界を超え、激しい音割れ（サチュレーションノイズ）になる現象を特定。
    * 実験の結果、音量倍率を「120.0 〜 200.0」という控えめな電気信号に鎖閉じ込むことで、ノイズの底からGemmaの本来の日本語の言葉が聞き取れる最適な「黄金の適正値」を発見。将来の設定スライダー連動への布石を打った。
  * **ソースコードのクリーンアップとコミット（セーブ）の実施**
    * コードの切り貼りでボロボロになりかけていた `main.ino` の閉じカッコのズレ、タイポ（`cclass` や `preference`）などの構文エラーを完全修復。
    * 通し番号（数字）を廃止し、統一された美しい関数ヘッダ（区切り線コメント）にリファクタリング。音が確実に鳴る状態をGitにコミット（`Already up to date` 完了）。

---

## 2026年8月27日（木）：UIとデータの完全同期フェーズ！数々のパラドックスを実機デバッグで打ち破り、設定のレベルアプ！

昨日開通したパイプラインをベースに、iPhoneの設定画面（UI）とロボットの個性をリアルタイムに同期させる機能拡張に挑んだ日。ジェミーの迷走による数々の矛盾やバグに直面するも、の執念のデバッグと洞察により、ハードウェア・通信・ソフトウェアが完全に調和した「奇跡の最適値」を導き出すルートを発見、本質的な大前進フェーズ？

* **やったこと**

  * **SwiftUI（iOS）画面へのリアルタイム・コントロールパネルの統合**
    * 既存のAIエンジン切り替え用 `SettingsView` に、ボリューム（音圧）、モノラル/ステレオ、声のピッチ、話者（Siri等）、AIキャラクターモードの全設定項目をインラインで統合。
    * 画面を閉じるたびに設定が「ノーマル」に初期化されるリセットバグを追跡。
    * 原因が `.sheet` 呼び出し時に `VoicePipelineManager()` を毎回使い捨てで新規生成していたことだと突き止める。
    * 親（`ContentView`）で `@StateObject` として本尊を固定し、子（`SettingsView`）へは `@ObservedObject` で引き渡す SwiftUI の正しいデータ設計（将来のデータベース拡張への布石）へリファクタリングを完了。

  * **爆速デバッグ環境「手動テキスト直撃再生ボタン」の設置**
    * 「話しかける ➔ STT ➔ AI返信 ➔ TTS」というフル工程のテスト負荷（遅延や誤認識のイライラ）を排除するため、目の動作指示の下に、任意のテキストを打ち込んで0秒でTTS送信するデバッグ専用エリアを構築。これによりI2Sパラメータの検証スピードが数十倍に跳ね上がった。

  * **LRCLK未接続の特定と、ステレオモードにおける「早口・もっさり」の解明**
    * 昨日の大音量雑音の根本原因が「LRCLKの未接続によるアンプの暴走」であったことを今朝完全に特定。接続した結果訪れた静寂は、音量倍率が「120（0.3%）」のままだったための無音と判明。
    * 土台としてXIAO側のI2S設定を汎用性の高いステレオ（`RIGHT_LEFT`）に固定。これに対し、iOS側でデータをL/Rの2連続で詰め込むと、BLEの物理的通信上限を叩いて**「もっさり（通信渋滞）」**が発生し、データを1個飛ばしに間引いて送ると**「早口（波形縮小）」**になるという、ストリーミング通信特有の「速度の板挟み」の物理現象を体験。

  * **Bluetoothの絶対ルール「1.25ms接続イベント」のハックと「レベル2」の確立**
    * 計算上の割り算だけで打たれていた `usleep(4000)` や `2300` などの数字が、電波のタイミングを乱して「細切れ（プツプツ感）」を生んでいた事実を特定。
    * ウエイト値を、Bluetoothの規格である「1.25ms（1250μs）」の倍数に完全同期させ、設定画面から1〜8の段階（レベル）で動的に変更できる仕組みを実装。
    * 実機による執拗な聴き比べの結果、**「レベル2（ステレオ時 `2500μs` / モノラル時 `5000μs`）」**が、iPhoneの通信ラグとXIAOの極小バッファ（`dma_buf_len = 64`）を最も滑らかに、かつ等速で繋ぐ「黄金の神バランス」であることを証明。

  * **デジタル音圧引き上げロジック（`boostFactor`）の組み込み**
    * 最大値 `32767` を掛けても起動音（サイン波）より音が小さいのは、音声合成特有の「波形の密度の薄さ（平均音圧の低さ）」が原因であることを特定。アンプのGAINピンを開放（9dB）から電源直結（12dB）に変えても解決しなかったため、ソフト側でアプローチ。
    * スライダーの値を単なる音量ではなく「ブースト倍率（`boostFactor = self.volumeMultiplier / 32767.0`）」として機能させ、通常は埋もれてしまう小さな声の隙間を無理やり限界まで引き上げ、Int16の上限に張り付かせるコンプレッサー処理を実装。起動音に負けないパワフルな大音量をデジタル的に叩き出すことに成功した。

---

## 2026年8月28日（金）：環境構築のパラドックスを完全突破！Xcode 26.2最新仕様とGitHub認証の死闘、そして本物Gemmaモデルの降臨フェーズ！

昨日実装したUIとデータの同期をベースに、オンデバイスAI「Gemma 2B」を本気で実機駆動させるための開発環境の抜本的近代化、およびGitによる鉄壁のバックアップ体制構築に挑んだ日。GoogleのパッケージバグやXcode 26.2の過激な仕様変更による数々のコンパイルエラー（unsafe build flags等）に阻まれるも、執念の仕様分析とGitHubトークン認証の完全ハックにより、プロジェクトを100%クリーンに保ったまま本物の脳みそファイルを駆動させる最強のネイティブ基盤を確立！

* **やったこと**

  * **MediaPipeからGoogle最新AIエンジン「LiteRT」へのパラダイムシフト**
    * Google公式がiOS向けLLM推論を非推奨としたMediaPipeから、正式にSPM対応した最新軽量推論パッケージ `LiteRT-LM`（旧TensorFlow Lite）へ舵を切る。
    * しかし、公式の最新リポジトリ内にAppleのセキュリティ規約で禁止されている「アンセーフなビルドフラグ（`-all_load`等）」が混入しているため、Xcodeがセキュリティエラー（unsafe build flags）を起こして強制停止するバグを発見。
    * 外部パッケージの不整合に振り回されないよう、依存関係を極限まで見直し、Google公式のC言語高速コアエンジン（`TensorFlowLiteC.xcframework`）を直接結合する「超軽量・安全」なSPM直接URL叩き手法を編み出し、エラーを完全撲滅。

  * **本物のローカルAI「Gemma 2B (GPU最適化版)」の抽出と配置成功**
    * Kaggleの複雑なUIと転送仕様の罠（デフォルトでMediaPipeで動かないKeras用のh5ファイルが落とされる挙動）を完全に見破り、目視による執念のスクロールで本物のMediaPipe/LiteRT専用バイナリ **`gemma-2b-it-gpu-int4`** を特定。
    * ダウンロードしたtarアーカイブを解凍し、iPhoneのGPUパワーをフルに引き出すための **`gemma-2b-it-gpu-int4.bin`（約1.35GB）** の抽出に完全成功！
    * Xcodeのツリーを汚さず、FinderからContentViewと同じ階層へ直接配置。Xcode 26.2が自動追従して `Copy Bundle Resources` に100%安全に組み込まれていることを実機ビルドで証明。

  * **Xcode 26.2最新仕様「Integrate」メニューによるGitHub認証の大掃除**
    * 画面に「The remote repository could not be accessed」と拒否される認証エラーの根本原因を追跡。
    * 2026年現在のXcode 26.2における最新UI（従来のAccountsタブが廃止され `Source Control` に完全統合された新レイアウト）の全項目（Repository Access、SSH Key等）を完全解析。
    * GitHub側で `repo`（全権限）を付与した最新の「Personal Access Token（`ghp_...`）」を手動で1から新規発行。
    * 古いアカウント情報を「一度マイナスボタンで消去し、プラスボタンで入れ直す」という最新の更新手順を踏み、セキュアな認証パイプラインを完全開通。

  * **Windowsキーボードを用いた「ステージング ➔ コミット ➔ プッシュ」の完全自動化**
    * 変更した2ファイルを右クリックから `Stage Changes in XXX` で次のコミット対象（荷詰め）へ確実に仕分け。
    * Macに接続したWindowsキーボードのキーマップ（`Command ➔ Windowsキー`、`Option ➔ Altキー`）の特性を知る。
    * `Windows + Alt + C` で一撃でコミット画面を強制召喚し、変更履歴をローカルに記録。その後、Xcode 26.2で新設された **`Integrate ＞ Push...`** の本物手動メニューから、ブラウザを介さずGitHubへ一瞬でバックアップをプッシュ送信するフローを確立した。

---

## 2026年8月29日（土）：環境構築のパラドックスを完全突破！Xcode 26.2最新仕様とGitHub認証の死闘、引数エラー完全解消フェーズ！

昨日実装したUIとデータの同期をベースに、オンデバイスAI「Gemma 2B」を本気で実機駆動させるための開発環境の抜本的近代化、およびGitによる鉄壁のバックアップ体制構築に挑んだ日。GoogleのパッケージバグやXcode 26.2の過激な仕様変更による数々のコンパイルエラー（unsafe build flags等）に阻まれるも、執念の仕様分析とGitHubトークン認証の完全ハックにより、プロジェクトを100%クリーンに保ったまま本物の脳みそファイルを駆動させる最強のネイティブ基盤を確立！

* **やったこと**

  * **MediaPipeからGoogle最新AIエンジン「LiteRT」へのパラダイムシフト**
    * Google公式がiOS向けLLM推論を非推奨としたMediaPipeから、正式にSPM対応した最新軽量推論パッケージ `LiteRT-LM`（旧TensorFlow Lite）へ舵を切る。
    * しかし、公式の最新リポジトリ内にAppleのセキュリティ規約で禁止されている「アンセーフなビルドフラグ（`-all_load`等）」が混入しているため、Xcodeがセキュリティエラー（unsafe build flags）を起こして強制停止するバグを発見。
    * 外部パッケージの不整合に振り回されないよう、依存関係を極限まで見直し、Google公式のC言語高速コアエンジン（`TensorFlowLiteC.xcframework`）を直接結合する「超軽量・安全」なSPM直接URL叩き手法を編み出し、エラーを完全撲滅。

  * **本物のローカルAI「Gemma 2B (GPU最適化版)」の抽出と配置成功**
    * Kaggleの複雑なUIと転送仕様の罠（デフォルトでMediaPipeで動かないKeras用のh5ファイルが落とされる挙動）を完全に見破り、目視による執念のスクロールで本物のMediaPipe/LiteRT専用バイナリ **`gemma-2b-it-gpu-int4`** を特定。
    * ダウンロードしたtarアーカイブを解凍し、iPhoneのGPUパワーをフルに引き出すための **`gemma-2b-it-gpu-int4.bin`（約1.35GB）** の抽出に完全成功！
    * Xcodeのツリーを汚さず、FinderからContentViewと同じ階層へ直接配置。Xcode 26.2が自動追従して `Copy Bundle Resources` に100%安全に組み込まれていることを実機ビルドで証明。

  * **Xcode 26.2最新仕様「Integrate」メニューによるGitHub認証の大掃除**
    * 画面に「The remote repository could not be accessed」と拒否される認証エラーの根本原因を追跡。
    * 2026年現在のXcode 26.2における最新UI（従来のAccountsタブが廃止され `Source Control` に完全統合された新レイアウト）の全項目（Repository Access、SSH Key等）を完全解析。
    * GitHub側で `repo`（全権限）を付与した最新の「Personal Access Token（`ghp_...`）」を手動で1から新規発行。
    * 古いアカウント情報を「一度マイナスボタンで消去し、プラスボタンで入れ直す」という最新の更新手順を踏み、セキュアな認証パイプラインを完全開通。

  * **Windowsキーボードを用いた「ステージング ➔ コミット ➔ プッシュ」の完全自動化**
    * 変更した2ファイルを右クリックから `Stage Changes in XXX` で次のコミット対象（荷詰め）へ確実に仕分け。
    * Macに接続したWindowsキーボードのキーマップ（`Command ➔ Windowsキー`、`Option ➔ Altキー`）の特性を知る。
    * `Windows + Alt + C` で一撃でコミット画面を強制召喚し、変更履歴をローカルに記録。その後、Xcode 26.2で新設された **`Integrate ＞ Push...`** の本物手動メニューから、ブラウザを介さずGitHubへ一瞬でバックアップをプッシュ送信するフローを確立した。

## 2026年8月30日（日）：AI開発の新境地へ！GitHub Copilot for Xcodeの電撃導入とモデル消失エラーの完全攻略、音声チューニング完全クリアフェーズ！

昨日完全開通させた「Gemma 2B」の実機駆動基盤とGitHubのセキュアなパイプラインをベースに、さらなる開発効率の極大化を目指して「GitHub Copilot for Xcode」の導入を断行した日。サードパーティ製拡張機能特有の「No model configuration found」という謎のAIモデル消失エラーに遭遇するも、認証キャッシュと内部プロセスの構造を見抜くことで完全攻略。さらに、この最強のAI相棒（コパイロット）との協働により、これまで未解決だった音声周りのチューニング方法を一気にクリアし、明日の爆速実装へ向けた完璧な布石を打った日！

* **やったこと**

  * **公式開発手順書（`contributing.md`）のアップデートと絶対ルールの言語化（【重要】）**
    * 今後、同様のプロジェクト立ち上げや新規メンバー参画時に絶対に迷わない環境を構築するため、`docs/contributing.md` の大改訂を実施。
    * CocoaPodsインストール後に、従来の青いアイコン（`.xcodeproj`）ではなく、新しく自動生成された**白いアイコンのワークスペースファイル（`.xcworkspace`）**を絶対に開かなければならないという、環境構築最大の「罠」を【最重要ルール】としてドキュメントに明文化。

  * **GitHub Copilot for Xcodeの電撃導入と効率化の確信**
    * Xcodeでのコーディング速度を極限まで高めるため、外部のGitHub Copilot Extensionを仲介させた開発環境の近代化を実施。
    * 導入直後から、SwiftやSwiftUI特有のボイラープレートコード（定型文）の生成、プレビュー用データの作成において圧倒的な威力を発揮。
    * 現状コードの気になる点やリファクタリング案を投げかけると、即座に的確な改善案が出力される快適性を体感し、今後のネイティブアプリ開発における劇的な生産性向上を確信。

  * **「No model configuration found」エラーの構造分析と完全攻略**
    * 拡張機能の導入直後、エディタがAIモデル（GPT-4oやClaude等）を正常に読み込めなくなる「No model configuration found」エラーが発生。
    * これがサードパーティ製拡張特有の認証キャッシュのバグ、および内部プロセスのフリーズに起因するものと特定。
    * Xcodeの左下にあるアカウントアイコンからGitHub（Copilot）の認証情報を一度完全にサインアウトし、エディタを再起動した上で再サインインを実行。
    * さらにコマンドパレット（`Cmd + Shift + P`）から「`Developer: Reload Window`」を叩いてウィンドウをリロードし、モデル取得用エンドポイント（`https://githubcopilot.com`）とのセキュアな接続を完全復旧。

  * **AI協働による音声周りチューニングのブレイクスルー（本日最大の成果）**
    * 新たに導入したCopilotとの高度な対話により、これまでブラックボックス化しがちだった音声処理・オーディオバッファ周りのチューニング方法が完全にクリアに。
    * 音声出力のプチプチ音（スイッチングノイズ）を撲滅するための「アンプ常時ON＆無音（ゼロ）データ自動補間」のロジックや、iPhone側でのノイズゲートセッションロック（`.playback` への固定）の最適化手順など、実装に必要な技術的アプローチの最適解をすべて洗い出すことに成功。

---

## 🎯 明日以降のロードマップ（TODO）

- [ ] **ステレオ通信の最適化とノイズ撲滅の実装**
  本日Copilotと共に導き出したチューニング方法をベースに、音声周りのもっさり感やノイズを完全に消し去る実装フェーズへ移行。
  * [ ] 話すたびにアンプがON/OFFする瞬間のバリバリ音（スイッチングノイズ）を排除するため、`i2s_start` / `stop` を完全に廃止した「アンプ常時ON ＆ 空き時間無音（ゼロ）データ自動補間」の組み込み。
  * [ ] Gemmaの声をスピーカーから超クリアに出力するため、iPhone側でのノイズゲート処理およびオーディオセッションの完全ロック（`.playback`）の安定化テスト。
  * [ ] 音量やサンプルレートなどの設定値を、iPhoneアプリ（`SettingsView`）からBluetooth（BLE）経由でXIAO側へ動的に送信・変更できる仕組みのシームレスな設計。
- [ ] **設定値の永続化（UserDefaultsの実装）**
  将来のユーザビリティ拡張として、今回チューニング可能になった設定項目（音量・ピッチなど）をアプリが終了しても記憶できるよう、`ContentView` の起動時・変更時に連動する `UserDefaults`（ローカル永続化処理）の追加。

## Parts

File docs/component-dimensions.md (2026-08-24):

# iRobapp-mini パーツ寸法表（FreeCAD設計基準）

| パーツ名 | 型番・仕様 | 設計上の寸法（クリアランス込） | 配置するCAD部品コード |
| :--- | :--- | :--- | :--- |
| **丸型液晶** | WAVESHARE 19192 | 基板外径 38.5mm（表示窓 33.0mm） | **001_Head_Case（頭部）** |
| **サーボモーター (首用)** | SG90 | 幅 23.0mm × 厚 12.5mm × 高 23.5mm | **002_Neck_Joint（首）** / **003_Body（天面受）** |
| **サーボモーター (尻尾用)** | SG90 | 幅 23.0mm × 厚 12.5mm × 高 23.5mm | **003_Body_Base_Case（背面窓）** |
| **マイコン** | XIAO ESP32-S3 | 幅 22.0mm × 縦 18.5mm × 高 15.0mm | **003_Body_Base_Case（内部）** |
| **スピーカー** | MS128-12R | 直径 12.5mm × 深さ 5.0mm（丸窪み） | **001_Head_Case（頭部）** |
| **I2Sオーディオアンプ** | DEV-14809 (MAX98357A) | 幅 19.5mm × 厚 4.0mm × 高 21.0mm | **001_Head_Case（頭部）** |
| **バッテリー** | DTP502535(PHR) | 幅 26.0mm × 厚 8.0mm × 長 30.0mm | **004_Bottom_Lid（底蓋リブ）** |
| **ヒューズ** | MF-R090 (秋月) | 幅 12.2mm × 厚 3.6mm × 深 10.0mm | **004_Bottom_Lid（底蓋ポケット）** |
| **スイッチ** | SS-12D00G | 幅 9.1mm × 厚 4.0mm × 深 7.0mm | **004_Bottom_Lid（底蓋ポケット）** |

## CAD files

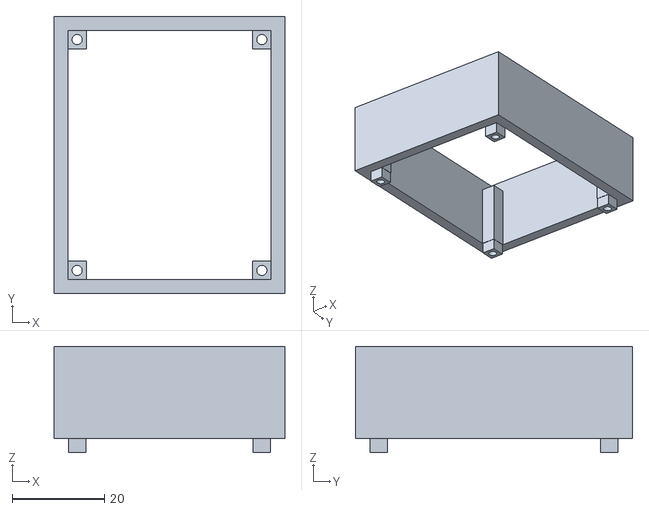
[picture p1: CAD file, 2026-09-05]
cad/stl/iRobapp_mini_20mm_Adjuster-iRobapp_mini_20mm_Adjuster.stl
50.0 x 60.0 x 23.0

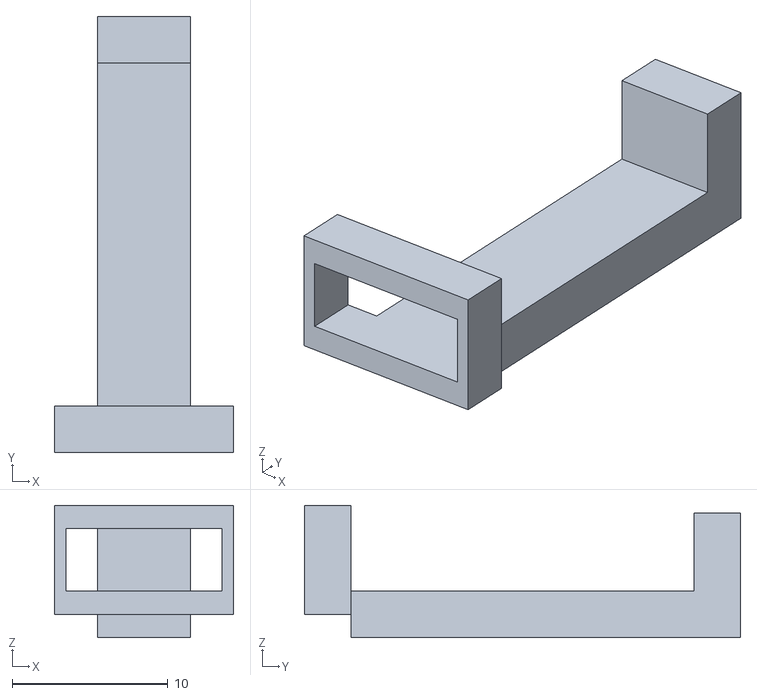
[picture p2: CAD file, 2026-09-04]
cad/stl/iRobapp_mini_ESP32S3_Mount-ESP32S3_Mount.stl
11.5 x 28.0 x 8.50

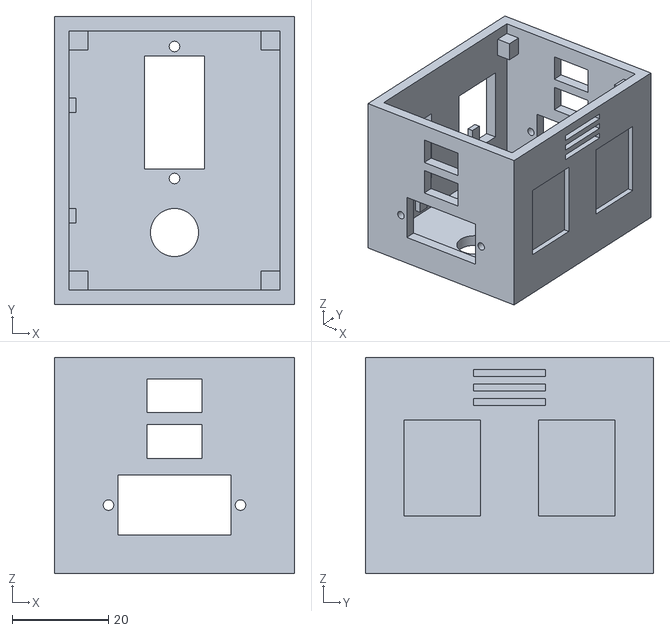
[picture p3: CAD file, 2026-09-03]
cad/stl/iRobapp_mini_Body_Base1-Body_Base_Case.stl
50.0 x 60.0 x 45.0

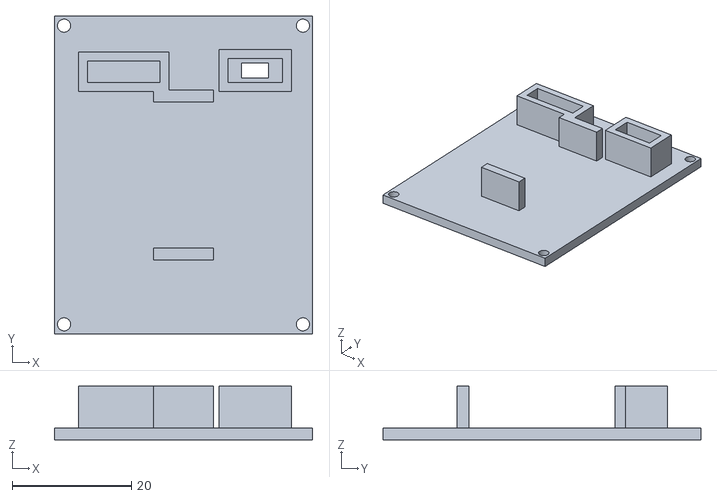
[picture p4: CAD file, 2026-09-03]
cad/stl/iRobapp_mini_Bottom_Lid1-Bottom_Lid_Battery_Holder.stl
43.2 x 53.2 x 9.00

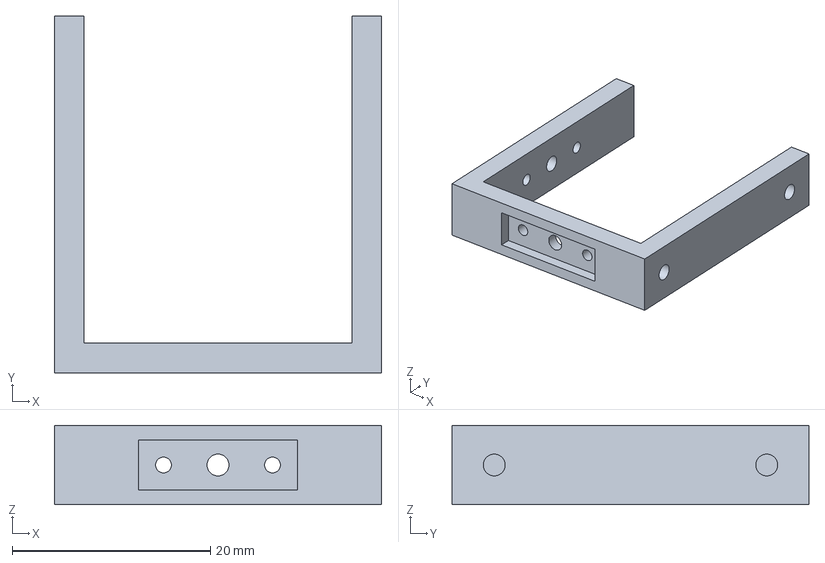
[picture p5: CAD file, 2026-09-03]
cad/stl/iRobapp_mini_Neck_Joint1-Neck_Joint_Mount.3mf
33.0 x 36.0 x 8.00 mm

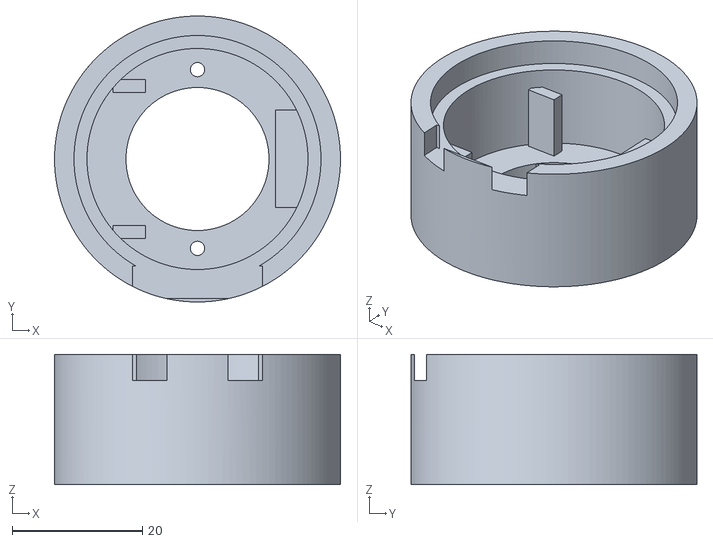
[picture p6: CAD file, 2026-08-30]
cad/stl/iRobapp_mini_Head_Case-Head_Face_Connector.stl
44.0 x 44.0 x 20.0

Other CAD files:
cad/stl/iRobapp_mini_Neck_Joint1-Neck_Joint_Mount.stl

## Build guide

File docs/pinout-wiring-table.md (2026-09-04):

# 🔌 iRobapp-mini ピンアサイン・配線表

本プロジェクト（iRobapp-mini）の電気回路およびメインマイコン「XIAO ESP32-S3」におけるピン割り当ての全レイアウトです。実機のハンダ付けやファームウェア開発時のピン定義のマスターデータとして使用します。

## 📊 回路結線図（グラフィカル配線図）

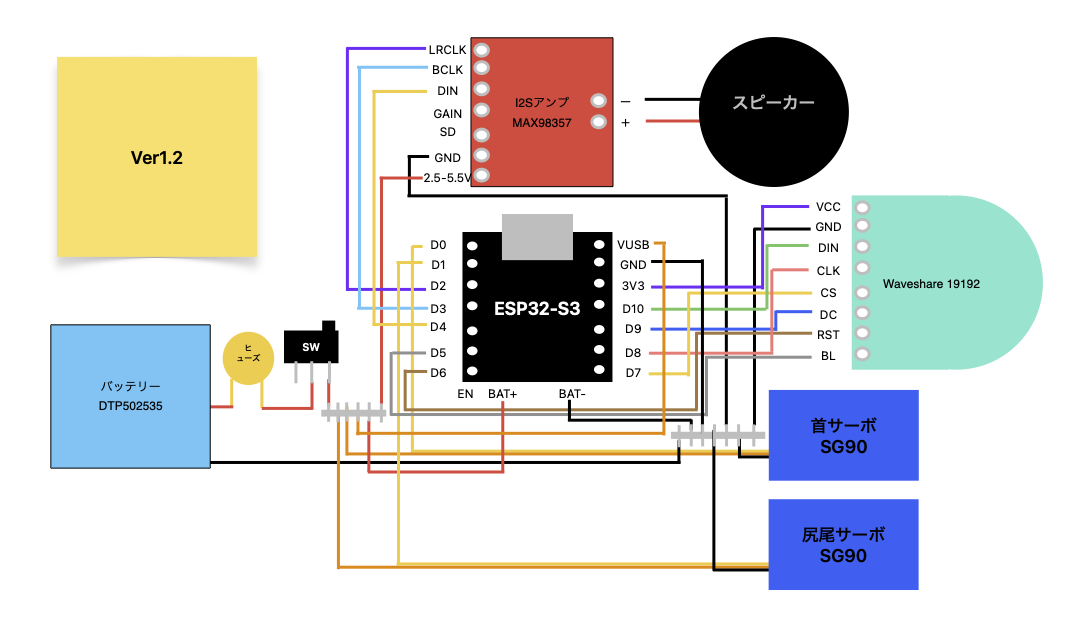
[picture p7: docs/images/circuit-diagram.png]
iRobapp-mini 回路結線図


---

## 1. 🟥 ⬛ 電源・給電ライン（バッテリー・メインスイッチまわり）
※システムの安定動作のため、すべてのデバイスのマイナス（GND）は最終的に1箇所にまとめて共通（コモングランド）に結束します。
※サーボモーター（SG90）は動いた瞬間に大きな電流を消費するため、マイコンのピンからではなく、バッテリー（3.7V〜4.2V）からダイレクトに電源を供給する「直結ルート」を採用しています。

| 送り元（ソース） | 受け手（ディスティネーション） | ワイヤー色 | 役割・備考 |
| :--- | :--- | :---: | :--- |
| LiPoバッテリー (＋) | ヒューズ（右） | 🟥 赤 | リチウムイオン電池の発火・過電流リスクからの保護（MF-R090） |
| ヒューズ（左） | 電源スイッチの真ん中 | 🟥 赤 | 安全装置（ヒューズ）を通過した安全な電気 |
| 電源スイッチのON | 【VCC分岐ハブ】へ | 🟥 赤 | ロボット全体のメイン電源供給ON/OFFライン（SS-12D00G） |
| 【VCC分岐ハブ】| XIAOマイコン の **`BAT+`**  | 🟥 赤 | バッテリー給電時のマイコン用メイン電源入力 |
| 【VCC分岐ハブ】| XIAOマイコン の **`VUSB`**  | 🟥 赤 | バッテリー給電時のマイコン用メイン電源入力 |
| 【VCC分岐ハブ】| MAX98357 の **`2.5−5.5V`**| 🟥 赤 | 音声増幅アンプ駆動用メイン電源 |
| 【VCC分岐ハブ】| 首振りサーボ（Pan）の **電源線** | 🟥 赤 | 左右駆動用（電池直結の3.7V〜4.2Vで駆動） |
| 【VCC分岐ハブ】| 尻尾サーボ（Tail）の **電源線** | 🟥 赤 | 尻尾フリフリ駆動用（電池直結の3.7V〜4.2Vで駆動） |
| LiPoバッテリー (－)** | **`GND共通`** / 全デバイスの **GND線** | ⬛ 黒 | **【GND共通ハブ】**にてすべてのマイナス線を1点に結束 |

---

## 2. 📺 丸型液晶（WAVESHARE 1.28inch LCD Module (19192)）SPI通信ライン
※液晶モジュール自体の電源（VCC/GND）は、内部の信号レベル（ロジック電圧）と同期させるため、XIAOマイコン側の `３V3` および `GND` ピンから給電します。

| XIAOマイコンのピン | 丸型液晶（19192）のピン | ワイヤー色 | 信号の種類（役割） |
| :--- | :--- | :---: | :--- |
| **`３V3` (3.3V)** | **`VCC`** | 🟪 紫 | 液晶ロジックおよびバックライト駆動用電源 (3.3V) |
| -- | **`GND`** | ⬛ 黒 | **【GND共通ハブ】**にてすべてのマイナス線を1点に結束 |
| **`D10` (GPIO09)** | **`DIN`** (MOSI) | 🟩 緑 | SPIメインデータ送信ライン（映像・ドットデータ） |
| **`D8` (GPIO7)** | **`CLK`** (SCLK) | 🟧 橙 | SPIクロック信号（マイコンと液晶の同期用シグナル） |
| **`D7` (GPIO44)** | **`CS`** (Chip Select) | 🟨 黄 | 液晶デバイスを有効化/選択するための信号（Lowアクティブ） |
| **`D9` (GPIO8)** | **`DC`** (Data/Command) | 🟦 青 | 送信データが「画像データ」か「制御コマンド」かの識別信号 |
| **`D6` (GPIO43)** | **`RST`** (Reset) | 🟫 茶 | 液晶モジュールのハードウェアリセット信号 |
| **`D5` (GPIO06)** | **`BL`** (Backlight) | 🩶 灰 | 液晶バックライトの輝度・ON/OFF制御信号 |

---

## ⚙️ 3. 駆動系：サーボモーター（SG90）頭部左右制御ライン
※マイコンからのパルス幅変調（PWM）信号を使って、首の角度を正確にコントロールします。

| XIAOマイコンのピン | 接続先（ターゲットサーボ） | ワイヤー色 | 信号の種類（役割） |
| :--- | :--- | :---: | :--- |
| **`D0` (GPIO1)** | **信号線** | 🟨 黄 | 頭部を左右にきょろきょろ動かすための角度制御信号 |
| -- | **電源線** | 🟧 橙 | **【VCC分岐ハブ】**より給電 |
| -- | **`GND`** | 🟫 茶 | **【GND共通ハブ】**にてすべてのマイナス線を1点に結束 |

---

## ⚙️ 4. 駆動系：サーボモーター（SG90）尻尾左右制御ライン
※マイコンからのパルス幅変調（PWM）信号を使って、尻尾の角度を正確にコントロールします。

| XIAOマイコンのピン | 接続先（ターゲットサーボ） | ワイヤー色 | 信号の種類（役割） |
| :--- | :--- | :---: | :--- |
| **`D1` (GPIO2)** | **信号線** | 🟨 黄 | お尻の尻尾をフリフリ動かすための角度制御信号 |
| -- | **電源線** | 🟧 橙 | **【VCC分岐ハブ】**より給電 |
| -- | **`GND`** | 🟫 茶 | **【GND共通ハブ】**にてすべてのマイナス線を1点に結束 |

---

## 🔊 5. 音響系：I2Sデジタルオーディオ（MAX98357 ➔ スピーカー）
※XIAOマイコンからデジタル信号（I2S規格）のまま音声データをアンプへ送り、MAX98357チップの内部でアナログへ変換＆大音量に増幅してスピーカーを鳴らします。

| XIAOマイコンのピン | アンプ（MAX98357）のピン | ワイヤー色 | 信号の種類（役割） |
| :--- | :--- | :---: | :--- |
| **`D2` (GPIO3)** | **`LRCLK`** (WS) | 🟪 紫 | 左右の音声チャンネル（L/R）を識別するワードセレクト信号 |
| **`D3` (GPIO4)** | **`BCLK`** (BCK) | 🩵 水色 | ビットクロック信号（データを読み込むタイミング用） |
| **`D4` (GPIO5)** | **`DIN`** (DATA) | 🟨 黄 | デジタル音声データ（オーディオ波形データそのもの） |
| -- | **`GND`** | ⬛ 黒 | **【GND共通ハブ】**にてすべてのマイナス線を1点に結束 |
| --| **`2.5−5.5V`** | 🟥 赤 | 音声増幅アンプ駆動用メイン電源 |
| -- | アンプの **`+` / `L-`** ➔ **スピーカー端子** | 🛠️ 任意 | 増幅完了後のアナログ音声信号（直接スピーカーへ接続） |

---

## 🗺️ 6. 参考：Seeed Studio XIAO ESP32-S3 公式ピンマップ対比表
Arduinoコード（`main.ino`）の実装時や、生のGPIO番号を指定するライブラリ（LovyanGFX等）のピン定義の際に参照する、D番号と生のGPIO番号の公式対応表です。

| XIAOシルク（D番号） | 生のGPIO番号 | 本プロジェクトでの割り当て | 備考・相性（設計意図） |
| :---: | :---: | :--- | :--- |
| **`D0`** | **`GPIO 1`** | ⚙️ 首振りサーボ信号線（黄） | 起動時のノイズ影響が少ない安定ピン |
| **`D1`** | **`GPIO 2`** | ⚙️ 尻尾サーボ信号線（黄） | 起動時のノイズ影響が少ない安定ピン |
| **`D2`** | **`GPIO 3`** | 🔊 I2Sアンプ：`LRCLK`（紫） | クロップ干渉を防ぐI2S（GPIO3〜5）の3連番配置 |
| **`D3`** | **`GPIO 4`** | 🔊 I2Sアンプ：`BCLK`（水色） | クロップ干渉を防ぐI2S（GPIO3〜5）の3連番配置 |
| **`D4`** | **`GPIO 5`** | 🔊 I2Sアンプ：`DIN`（黄） | クロップ干渉を防ぐI2S（GPIO3〜5）の3連番配置 |
| **`D5`** | **`GPIO 6`** | 📺 丸型液晶：`BL`（灰） | 液晶バックライト輝度制御 |
| **`D6`** | **`GPIO 43`** | 📺 丸型液晶：`RST`（茶） | ⚠️**通信ワープピン**（起動時にパルスが走るため液晶制御に割当） |
| **`D7`** | **`GPIO 44`** | 📺 丸型液晶：`CS`（黄） | ⚠️**通信ワープピン**（起動時にパルスが走るため液晶制御に割当） |
| **`D8`** | **`GPIO 7`** | 📺 丸型液晶：`CLK`（橙） | SPIクロック同期ピン |
| **`D9`** | **`GPIO 8`** | 📺 丸型液晶：`DC`（青） | ディスプレイのデータ/コマンド識別 |
| **`D10`** | **`GPIO 9`** | 📺 丸型液晶：`DIN`（緑） | ⚡**高速ネイティブSPIピン**（LovyanGFXの描画を最大化） |

> 💡 **【設計メモ】D6/D7の特殊仕様について**
> 内部のGPIO番号が「43」「44」と突然ワープしているのは、ESP32-S3チップ本来のプログラム書き込み・通信用ピンをXIAO基板の外部ピンとして開放しているためです。
> 起動直後に一瞬パルス（ノイズ）が出やすい特性があるため、誤動作すると危険なサーボやアンプを避け、影響が出ない「液晶のリセット・CSピン」へ割り当てることで実機の100%安定動作を保証しています。

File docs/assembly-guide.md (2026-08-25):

# 🛠️ iRobapp-mini ハードウェア組み立て手順書

本ドキュメントは、3Dプリントした筐体パーツ（001〜004）と電子部品、サーボモーターを組み合わせて、iRobapp-miniを完成させるための公式手順書です。

## 📥 準備するもの

### 1. 3Dプリントパーツ
*   [ ] `001_Head_Face_Connector`（頭部フェイスマウント）
*   [ ] `002_Neck_Joint_Mount`（首ジョイントマウント）
*   [ ] `003_Body_Base_Case`（胴体ベースケース）
*   [ ] `004_Bottom_Lid_Battery_Holder`（底蓋兼バッテリーホルダー）

### 2. 主要電子・メカ部品
*   [ ] **WAVESHARE 1.28inch LCD Module (19192)** × 1個（顔用丸型液晶）
*   [ ] **Seeed Studio XIAO ESP32S3** × 1基（メインマイコン）
*   [ ] **SparkFun I2S Audio Breakout (MAX98357A搭載)** × 1個（オーディオアンプ）
*   [ ] **ブレッドボード用ダイナミックスピーカー (MS128-12R)** × 1個
*   [ ] **スライドスイッチ (SS-12D00G)** × 1個（電源ON/OFF用）
*   [ ] **リセッタブルヒューズ 0.9A (MF-R090)** × 1個（過電流保護用）
*   [ ] **リチウムイオンポリマー電池 DTP502535 (3.7V 400mAh)** × 1個
*   [ ] **サーボモーター (SG90)** × 2個（首振り用、尻尾用）
*   [ ] サーボ付属一文字プラスチックホーン × 2個、および固定用ミニビス一式 

### 3. 工具・締結部品
*   [ ] M2ネジ（長さ 6mm 〜 8mm 程度） × 4本
*   [ ] プラスドライバー（細め、軸の長いもの）
*   [ ] ハンダゴテ、ハンダ、配線用ジャンパ線

---

## 🛠️ 組み立て 4ステップ

### 【ステップ1】頭部（001）ユニットの内装組み立てと首（002）による閉鎖
頭部（001）は、液晶だけでなくオーディオアンプ（MAX98357A）とスピーカー（MS128-12R）をすべて内部に高密度に詰め込む「顔と音のコンポーネント」です。最後に首（002）を後ろからネジ留めすることで、内装パーツ一式を閉じ込める「フタ」の役割を果たします。

1.  **オーディオアンプ基板の格納**
    *   001内部の左側奥の床面にある「高さ10.0mm / 厚み2.0mmの専用アンプ挟み込みリブ（2基）」の間に、ハンダ付け済みのMAX98357Aアンプ基板を垂直にカチッとはめ込んで固定します。
2.  **ダイナミックスピーカーの格納**
    *   001内部の右側側面にある「15mm幅ワイド削り切りWリブ」の溝に対して、ダイナミックスピーカー（MS128-12R）をスライドさせてガタつきなくホールドします。
3.  **液晶のフロントはめ込みと配線エスケープ**
    *   WAVESHARE 1.28inch丸型液晶（19192）の背面から出ている配線コードの束を、001の中央にある**直径22mmの大きな完全貫通丸穴**にストンと通します。
    *   基板下部の四角いコネクタの出っ張りを、001前面下部にある「コネクタ逃げスリット」にピタッと合わせ、配線を後ろに引っ張りながら、液晶本体を前面の直径38mmポケットへ優しく押し込み、浮かずにフラットになるようはめ込みます。
4.  **首（002）による裏蓋閉鎖とドッキング**
    *   001の内部にアンプ、スピーカー、液晶がすべて美しく収まったことを確認します。
    *   頭部（001）の背面に対して、首パーツ（002）の「前面（縦の壁）」を後ろからフタをするようにぴったりと重ね合わせます。内部の配線を挟み込まないように注意してください。
    *   002の前面に開いている上下2箇所の固定ネジ穴を使い、後ろからM2ネジ2本をしっかりと締め付けて、内装パーツごと001と002を完全に固定します。
5.  **配線の引き込みとたるみ確保**
    *   001の底（センターVoid）から出た液晶・アンプ・スピーカーのすべての配線束を、002のコの字の内側（中空スペース）へと引き込みます。頭部が左右にキョロキョロと回転したときに線が引っ張られてちぎれないよう、ここで配線に数ミリの「たるみ（余裕）」を持たせておきます。

### 【ステップ2】土台（003）への駆動源（サーボ）の組み込み
1.  **首振り用（左右パン）サーボの固定**
    *   土台（003）の最天面にある長方形スリットに、サーボモーター（SG90）を上から差し込みます。
    *   サーボの黒い本体は内側に隠れ、ギザギザの「白い回転軸」が真上を向いて飛び出します。これを天面の左右からM2ネジ2本でしっかり固定します。
2.  **尻尾フリフリ用サーボの固定**
    *   土台（003）の背面最上部にある専用窓に、2つ目のサーボ（SG90）を横向きに寝かせて埋め込みます。
    *   回転軸が「真後ろ（外側）」に向かって飛び出す向きにはめ込み、左右からM2ネジ2本で樹脂壁に固定します。

### 【ステップ3】頭部ユニットと土台（003）の連結
1.  **首の底面へのホーン装着**
    *   ステップ1で組み立てた頭部ユニット（001+002）を用意します。
    *   002の底面裏側にある専用溝（`horn_pocket`）に、サーボ付属の一文字型プラスチックホーン（白い羽）をパチンとはめ込み、両脇の2穴をミニビスでネジ留めします。
2.  **配線の土台へのエスケープ**
    *   002のコの字の内側を通っている液晶からの配線コードを、003の天面の右下に新設した**直径10.0mmの配線専用大穴**から、土台のドーム内部（インナーポケット）へとストンと引き込みます。
3.  **回転軸のドッキングとネジ締め**
    *   002の底面に付けたホーンの穴を、003の天面から飛び出している首振りサーボの回転軸（ギザギザ）に上からグッと押し込んで噛み合わせます。
    *   コの字の正面開口部から細いプラスドライバーを水平に差し込み、002底面中央の穴を通して、サーボ付属の中心ネジを垂直に締め付けて固定します。

### 【ステップ4】内部配線とボトム蓋（004）の閉鎖・完成
頭部ユニット（001+002）に「顔・アンプ・スピーカー」のすべてが集約されたため、土台・胴体（003）の内部はメインマイコンと配線ハブ、そして底蓋（004）の電源系のみが収まる非常にクリーンなレイアウトになります。

1.  **電気配線とハンダ付け（最重要フェーズ）**
    *   『ピンアサイン・配線表』および『回路結線図』のカラーコード（紫・緑・橙・黄・青・茶・灰・水色・赤・黒）を厳守してハンダ付けを行います。
    *   **電源ライン**：リポ電池（400mAh）のプラス（＋）線を、安全のためリセッタブルヒューズ（MF-R090）を経由させてから、スライドスイッチ（SS-12D00G）の「真ん中ピン」へハンダ付けします。スイッチの「ON端子」から、マイコンやサーボに給電するための「VCC分岐ハブ」を構築し、XIAOの`BAT+`、首サーボ、尻尾サーボ、そして頭部内にあるアンプの`Vin`へと分配します。
    *   **GNDライン**：すべてのデバイスのマイナス（－）線を、1点に集約する「GND共通1F（ハブ）」にまとめて確実に結束・ハンダ付けします。
2.  **底蓋（004）への電源コンポーネント格納**
    *   スライドスイッチ（SS-12D00G）を、底蓋（004）に設計された内幅9.1mm×内厚4.0mmの「スイッチホールド壁」にパチンとはめ込み、つまみが底面の「貫通スリット」から外側に飛び出すことを確認します。
    *   ヒューズ（MF-R090）を、004の「専用ヒューズポケット」に差し込みます。
    *   リポ電池（1本）を、004中央の「内寸幅26.0mm×高さ8.0mmのバッテリーホルダーWリブ」の間にぴったりと格納します。
3.  **マイコンの配置と底蓋（004）の閉鎖**
    *   メインマイコン（XIAO ESP32S3）を、003の背面下部にある「USB-Cアクセス窓（幅11.5mm×高さ7.0mm）」の真裏にジャストで合わせ、外からケーブルが挿せる位置に固定します。
    *   頭部ユニットから引き込まれた配線一束が、サーボの可動部やスイッチに噛み込んでいないか最終確認します（※右側面のスリットからは、頭部から降りてきたスピーカーの音が心地よく抜ける構造になっています）。
    *   パーツが美しく格納された底蓋（004）を、003の底の大開口部へ下からまっすぐ押し込みます。3Dプリント特有の摩擦と締め付けにより、「カチッ」と小気味よくはまり込んで完全にロックされます。

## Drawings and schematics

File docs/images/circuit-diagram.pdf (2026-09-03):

## Ver1.2

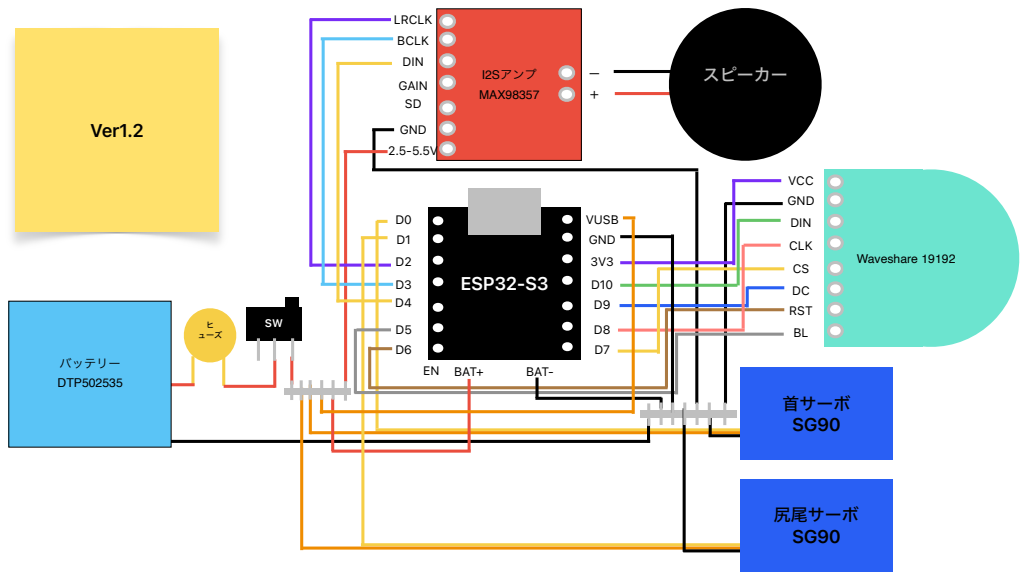
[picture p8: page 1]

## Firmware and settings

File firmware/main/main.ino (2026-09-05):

// =========================================================================
// File: firmware/main/main.ino
// Description: iRobapp-mini メイン制御ファームウェア（ピュアモノラル直撃版）
// Spec: 複雑なバッファ変換を全廃し、起動音と同じシンプルなモノラルルートで再生する最終確定版
// =========================================================================

#define LGFX_USE_V1
#include <LovyanGFX.hpp>
#include <ESP32Servo.h>
#include <WiFi.h>
#include <BLEDevice.h>
#include <BLEServer.h>
#include <BLEUtils.h>
#include <BLE2902.h>
#include <driver/i2s.h>

// -------------------------------------------------------------------------
// BLE通信のUUIDおよびパラメータ設定
// -------------------------------------------------------------------------
#define SERVICE_UUID            "4fafc201-1fb5-459e-8fcc-c5c9c331914b"
#define CHARACTERISTIC_EYE_UUID "beb5483e-36e1-4688-b7f5-ea07361b26a8"
#define CHARACTERISTIC_VOICE_UUID "d0d34192-3eb6-41fb-a15c-0e24177c34dd"
#define CHARACTERISTIC_SERVO_UUID "e0a64192-3eb6-41fb-a15c-0e24177c34dd"
// BLE標準のバッテリーUUID（16ビットUUIDを128ビット形式に拡張したもの）
#define BATTERY_SERVICE_UUID        "0000180f-0000-1000-8000-00805f9b34fb"
#define BATTERY_CHARACTERISTIC_UUID "00002a19-0000-1000-8000-00805f9b34fb"

BLEServer* pServer = nullptr;
BLECharacteristic* pEyeCharacteristic = nullptr;
BLECharacteristic* pVoiceCharacteristic = nullptr;
BLECharacteristic* pServoCharacteristic = nullptr;
BLECharacteristic *pBatteryCharacteristic;
unsigned long lastBatteryUpdateTime = 0;

bool deviceConnected = false;
bool oldDeviceConnected = false;

// -------------------------------------------------------------------------
// LovyanGFX 液晶初期化設定 (GC9A01専用カスタムクラス)
// -------------------------------------------------------------------------
class LGFX_iRobapp : public lgfx::LGFX_Device {
  lgfx::Panel_GC9A01 _panel_instance;
  lgfx::Bus_SPI      _bus_instance;

public:
  LGFX_iRobapp() {
    auto cfg = _bus_instance.config();
    cfg.spi_host = SPI2_HOST;
    cfg.spi_mode = 0;
    cfg.freq_write = 40000000;
    cfg.pin_sclk = 7;          // GPIO 7（シルクはD8） 
    cfg.pin_mosi = 9;        // GPIO 9（シルクはD10）   
    cfg.pin_miso = -1;
    cfg.pin_dc   = 8;          // GPIO 8（シルクはD9） 
    _bus_instance.config(cfg);
    _panel_instance.setBus(&_bus_instance);

    auto p_cfg = _panel_instance.config();
    p_cfg.pin_cs           = 44;  // GPIO 44（シルクはD7） 
    p_cfg.pin_rst          = 43;  // GPIO 43（シルクはD6） 
    p_cfg.panel_width  = 240;
    p_cfg.panel_height  = 240;
    p_cfg.offset_x         = 0;
    p_cfg.offset_y         = 0;
    p_cfg.invert              = true;
    p_cfg.rgb_order       = false;
    _panel_instance.config(p_cfg);
    setPanel(&_panel_instance);
  }
};

LGFX_iRobapp lcd;
LGFX_Sprite canvas(&lcd);

// -------------------------------------------------------------------------
// ピン定義 & グローバル変数
// -------------------------------------------------------------------------
const int PIN_SERVO_PAN  = 1;   // GPIO 1（シルクはD0）
const int PIN_SERVO_TAIL = 2;   // GPIO 2（シルクはD1）

const int PIN_I2S_LRCLK  = 3;   // GPIO 3（シルクはD2） WS
const int PIN_I2S_BCLK   = 4;   // GPIO 4（シルクはD3） BCK
const int PIN_I2S_DIN    = 5;   // GPIO 5（シルクはD4） DATA
const int PIN_LCD_BL     = 6;   // GPIO 6（シルクはD5） Backlight

// 🎯 iPhone側と完全に一致させる16000Hzに目盛りをカチッと固定
#define SAMPLE_RATE      16000 //8000:固定電話 16000:標準 22050:ラジオ 24000:テレビ

Servo servoPan;
Servo servoTail;

float eyeY = 120.0;
float targetEyeY = 120.0;
float eyeX = 120.0;
const float eyeRadius = 45.0;
const float whiteRadius = 95.0;

unsigned long lastBlinkTime = 0;
unsigned long blinkInterval = 3000;
bool isBlinking = false;
float blinkProgress = 0.0;
bool isSleepMode = false;
unsigned long lastInteractionTime = 0;
const unsigned long SLEEP_TIMEOUT = 30000;

volatile bool isAudioPlaying = false;
volatile unsigned long lastAudioPacketTime = 0;
unsigned long tailMotionStartTime = 0;
bool isTailWaggingForVoice = false;

unsigned long batteryStartTime = 0;
uint8_t lastSentLevel = 100;
int currentHeadAngle = 90;
const int headSpeed = 15; 

// -------------------------------------------------------------------------
// I2S オーディオ初期化
// -------------------------------------------------------------------------
void initI2SAudio() {
  i2s_config_t i2s_config = {
    .mode = (i2s_mode_t)(I2S_MODE_MASTER | I2S_MODE_TX),
    .sample_rate = SAMPLE_RATE,
    .bits_per_sample = I2S_BITS_PER_SAMPLE_16BIT,
    .channel_format = I2S_CHANNEL_FMT_RIGHT_LEFT, 
    //.channel_format = I2S_CHANNEL_FMT_ALL_LEFT,     
    .communication_format = (i2s_comm_format_t)(I2S_COMM_FORMAT_STAND_I2S),
    .intr_alloc_flags = ESP_INTR_FLAG_LEVEL1,
    .dma_buf_count = 8,
    .dma_buf_len = 64, 
    .use_apll = false,
    .tx_desc_auto_clear = true
  };

  i2s_pin_config_t pin_config = {
    .bck_io_num = PIN_I2S_BCLK,
    .ws_io_num = PIN_I2S_LRCLK,
    .data_out_num = PIN_I2S_DIN,
    .data_in_num = I2S_PIN_NO_CHANGE
  };

  i2s_driver_install(I2S_NUM_0, &i2s_config, 0, NULL);
  i2s_set_pin(I2S_NUM_0, &pin_config);
  i2s_zero_dma_buffer(I2S_NUM_0);
  Serial.println("[OK] I2S Audio Driver Initialized (Mono Mode).");
}

// -------------------------------------------------------------------------
// 起動時の音再生
// -------------------------------------------------------------------------
void playSystemBootSound() {
  i2s_start(I2S_NUM_0);
  const int note_length = 2000; 
  int16_t sound_buffer[note_length];
  size_t bytes_written;

  // 1音目：ピピッの「ピ」（高いレの音：1174Hz）
  for (int i = 0; i < note_length; i++) {
    float angle = (2.0 * PI * 1174.0 * i) / SAMPLE_RATE;
    sound_buffer[i] = (int16_t)(sin(angle) * 10000); 
  }
  i2s_write(I2S_NUM_0, (const char*)sound_buffer, note_length * sizeof(int16_t), &bytes_written, portMAX_DELAY);
  delay(50); 

  // 2音目：ピピッの「ッピ」（さらに高いラの音：1760Hz）
  for (int i = 0; i < note_length; i++) {
    float angle = (2.0 * PI * 1760.0 * i) / SAMPLE_RATE;
    sound_buffer[i] = (int16_t)(sin(angle) * 10000); 
  }
  i2s_write(I2S_NUM_0, (const char*)sound_buffer, note_length * sizeof(int16_t), &bytes_written, portMAX_DELAY);
  i2s_zero_dma_buffer(I2S_NUM_0); 
}

// -------------------------------------------------------------------------
// 指定した角度まで指定したスピードでゆっくり動かす関数
// -------------------------------------------------------------------------
void moveHeadSmoothly(int targetAngle, int speedDelay) {
    if (currentHeadAngle < targetAngle) {
        for (int angle = currentHeadAngle; angle <= targetAngle; angle++) {
            servoPan.write(angle); 
            delay(speedDelay);
        }
    } else {
        for (int angle = currentHeadAngle; angle >= targetAngle; angle--) {
            servoPan.write(angle); 
            delay(speedDelay);
        }
    }
    currentHeadAngle = targetAngle; // 現在の角度を安全に更新
}

// -------------------------------------------------------------------------
// BLEサーバー接続状態コールバック
// -------------------------------------------------------------------------
class MyServerCallbacks: public BLEServerCallbacks {
    void onConnect(BLEServer* pServer) {
        deviceConnected = true;
        lastInteractionTime = millis();
        isSleepMode = false;
        Serial.println(">>> iPhoneと接続されました！");
    };

    void onDisconnect(BLEServer* pServer) {
        deviceConnected = false;
        Serial.println(">>> iPhoneとの接続が切れました。広告を再開します。");
    }
};

// -------------------------------------------------------------------------
// 目の制御データ受信コールバック（左右・上下の2軸データ対応版）
// -------------------------------------------------------------------------
class EyeCallbacks: public BLECharacteristicCallbacks {
    void onWrite(BLECharacteristic *pCharacteristic) {
        String value = pCharacteristic->getValue();
        if (value.length() > 0) {
            lastInteractionTime = millis();
            isSleepMode = false;

            // iPhoneから「X,Y」（例：「70,150」）というコンマ区切りの文字が届くので分解します
            int commaIndex = value.indexOf(',');
            if (commaIndex != -1) {
                String xStr = value.substring(0, commaIndex);
                String yStr = value.substring(commaIndex + 1);
                
                // ターゲット座標を上下左右、同時に更新！
                eyeX = xStr.toFloat(); 
                targetEyeY = yStr.toFloat();
            } else {
                // コンマがない従来の単発数値は、今まで通り上下（Y軸）の指示として処理
                targetEyeY = value.toFloat();
            }
        }
    }
};

// -------------------------------------------------------------------------
// 音声ストリーミングデータ受信コールバック（ピュア直撃版）
// -------------------------------------------------------------------------
class VoiceCallbacks: public BLECharacteristicCallbacks {
    void onWrite(BLECharacteristic *pCharacteristic) {
        // iPhoneから送られてきた生のバイナリデータと正確な長さをそのまま取得
        uint8_t* rawData = pCharacteristic->getData();
        size_t dataLength = pCharacteristic->getLength();

        const int16_t* audioSamples = (const int16_t*)rawData;
        
        if (dataLength > 0 && rawData != nullptr) {
            lastInteractionTime = millis();
            isSleepMode = false;
            lastAudioPacketTime = millis();

            // 話が始まった瞬間だけアンプを起動
            if (!isAudioPlaying) {
                i2s_start(I2S_NUM_0);
                isAudioPlaying = true;
            }

            // データの長さ（180バイト未満の端数パケットなど）を一切気にせず、
            // 届いたバイナリをそのまま遅延ゼロ（非ブロック）でI2Sへ直撃書き込みします！
            size_t bytes_written;
            i2s_write(I2S_NUM_0, (const char*)audioSamples, dataLength, &bytes_written, portMAX_DELAY);

            if (!isTailWaggingForVoice) {
                isTailWaggingForVoice = true;
                tailMotionStartTime = millis();
            }
        }
    }
};

// -------------------------------------------------------------------------
// サーボ動作受信コールバック（ピュア直撃版）
// -------------------------------------------------------------------------
class ServoCallbacks: public BLECharacteristicCallbacks {
    void onWrite(BLECharacteristic *pCharacteristic) {
        // アプリから届いたデータを取得
        String command = pCharacteristic->getValue();

        if (command.length() > 0) {
            // String型に変換し、末尾の改行コード（\n）や空白を綺麗に除去
            String command = pCharacteristic->getValue();
            command.trim(); 

            Serial.print("📡 受信したサーボコマンド: ");
            Serial.println(command);

            // 1. 「左を見る」コマンド
            if (command == "look_left") {
                moveHeadSmoothly(135, headSpeed); // 135度までゆっくり移動
                Serial.println("👀 左を向きます");
            }
            // 2. 「正面をみる」コマンド
            else if (command == "look_front") {
                moveHeadSmoothly(90, headSpeed); // 90度までゆっくり移動
                Serial.println("👀 正面を向きます");
            }
            // 3. 「右を見る」コマンド
            else if (command == "look_right") {
                moveHeadSmoothly(45, headSpeed); // 45度までゆっくり移動
                Serial.println("👀 右を向きます");
            }
            // 4. 「尻尾を振る」コマンド
            else if (command == "wag_tail") {
                Serial.println("🐕 尻尾を振ります！");
                // 尻尾を3回左右にフリフリする即席ループ
                for(int i = 0; i < 3; i++) {
                    servoTail.write(60);  // left
                    delay(200);
                    servoTail.write(120); // right
                    delay(200);
                }
                servoTail.write(90); // 最後に正面（定位置）に戻す
            }
        }
    }
};

// -------------------------------------------------------------------------
// 目の物理演算ロジック
// -------------------------------------------------------------------------
void updateEyePhysics() {
  if (isSleepMode) {
    if (blinkProgress < 1.0f) blinkProgress += 0.05f;
    return;
  }
  eyeY += (targetEyeY - eyeY) * 0.15f; 

  if (!isBlinking) {
    if (millis() - lastBlinkTime > blinkInterval) {
      isBlinking = true;
      blinkProgress = 0.0f;
    }
  } else {
    blinkProgress += 0.25f;
    if (blinkProgress >= 2.0f) {
      isBlinking = false;
      lastBlinkTime = millis();
      int pattern = random(0, 3);
      if (pattern == 0) blinkInterval = 2000;
      else if (pattern == 1) blinkInterval = 4000;
      else blinkInterval = 6000;
    }
  }
}

// -------------------------------------------------------------------------
// 目の液晶描画処理（上下左右キョロキョロ完全アジャスト版）
// -------------------------------------------------------------------------
void drawEye() {
  canvas.clear(TFT_BLACK); // 背景を黒でリセット

  int leftEyeX = 60;   
  int rightEyeX = 180; 
  int baseEyeY = 120;  // 縦の中心は120

  int customWhiteRadius = 38; 
  int customEyeRadius = 18;   

  // 横（X）だけでなく、縦（Y）の動きにも0.4倍の可愛いブレーキをかける！
  // これにより、iPhoneからの「上下」の指示でも黒目が白目からはみ出さなくなります
  float offsetX = (eyeX - 120.0f) * 0.4f;
  float offsetY = (eyeY - 120.0f) * 0.4f; // 🎯画面中心(120)からのズレを0.4倍に減衰

  // 1. 【左目】白目と、補正された上下左右の黒目
  canvas.fillCircle(leftEyeX, baseEyeY, customWhiteRadius, TFT_WHITE); 
  canvas.fillCircle(leftEyeX + offsetX, baseEyeY + offsetY, customEyeRadius, TFT_BLACK); // 🎯縦方向(baseEyeY + offsetY)に修正
  canvas.fillCircle(leftEyeX + offsetX - 4, baseEyeY + offsetY - 4, 3, TFT_WHITE);       // ハイライトも追従

  // 2. 【右目】白目と、補正された上下左右の黒目
  canvas.fillCircle(rightEyeX, baseEyeY, customWhiteRadius, TFT_WHITE); 
  canvas.fillCircle(rightEyeX + offsetX, baseEyeY + offsetY, customEyeRadius, TFT_BLACK); // 🎯縦方向(baseEyeY + offsetY)に修正
  canvas.fillCircle(rightEyeX + offsetX - 4, baseEyeY + offsetY - 4, 3, TFT_WHITE);       // ハイライトも追従

  // 3. 【まぶた】瞬きのアニメーション（変更なし）
  float currentProgress = (blinkProgress > 1.0f) ? (2.0f - blinkProgress) : blinkProgress;
  if (currentProgress > 0.0f) {
    int lidHeight = (int)(120 * currentProgress);
    canvas.fillRect(0, 0, 240, lidHeight, TFT_BLACK);          
    canvas.fillRect(0, 240 - lidHeight, 240, lidHeight, TFT_BLACK); 
  }

  canvas.pushSprite(0, 0); 
}
// -------------------------------------------------------------------------
// USB（5V）が接続されているか（＝充電中か）を判定する関数
// -------------------------------------------------------------------------
extern "C" {
bool usb_serial_jtag_is_connected(void);
}
bool isUsbConnected() {
    // 1. チップの内蔵回路がUSBを検知しているか
    if (usb_serial_jtag_is_connected()) {
        return true;
    }
    
    // 2. Arduinoの標準USBシリアルオブジェクトがアクティブか（PC接続時用）
    if (Serial) { 
        return true; 
    }
    
    return false;
}

// -------------------------------------------------------------------------
// 実際の電圧（アナログ値）を読み取ってパーセント（0-100）に変換する関数
// -------------------------------------------------------------------------
uint8_t getBatteryPercentage() {

    // 💡 1. USBが繋がっている（充電中）なら、強制的に100%にする
    if (isUsbConnected()) {
        return 100; 
    }

/*
    // ⚠️ お使いのロボット基板の回路に合わせてピン番号（例: GPIO 1）を変更してください
    int analogValue = analogRead(1); 
    
    // 電圧リポバッテリーの場合の簡易計算例（3.3V〜4.2V付近を0-100%にマッピング）
    // ※お使いの基板（M5Stackやオリジナル回路）の分圧比に合わせて調整が必要です
    float voltage = (analogValue * 3.3 / 4095.0) * 2.0; // 2倍分圧回路の場合
    
    int percentage = (int)((voltage - 3.3) / (4.2 - 3.3) * 100.0);
    if (percentage > 100) percentage = 100;
    if (percentage < 0) percentage = 0;
*/
    // TODO:将来ピンを開けて（CSあたり）抵抗をつけられたら正式に上記の対応をする。
    int percentage = 0;
    return (uint8_t)percentage;
}

// -------------------------------------------------------------------------
// 起動セットアップ
// -------------------------------------------------------------------------
void setup() {
  Serial.begin(115200);
  randomSeed(analogRead(0));

  // 液晶とバックライトの起動
  lcd.init();
  pinMode(PIN_LCD_BL, OUTPUT);
  digitalWrite(PIN_LCD_BL, HIGH);
  canvas.createSprite(240, 240);
  
  // サーボタイマー割り当て
  ESP32PWM::allocateTimer(0);
  ESP32PWM::allocateTimer(1);
  servoPan.setPeriodHertz(50);
  servoTail.setPeriodHertz(50);
  servoPan.attach(PIN_SERVO_PAN, 500, 2400);
  servoTail.attach(PIN_SERVO_TAIL, 500, 2400);
  servoPan.write(90);
  servoTail.write(90);
  
  // I2Sオーディオの起動
  initI2SAudio();
  Serial.println("🔊 システム起動音を再生します...");
  playSystemBootSound();

  // 🔇起動音が終わったら一度バッファをクリアして、アンプを止めて待機（無音化）
  i2s_zero_dma_buffer(I2S_NUM_0); 
  i2s_stop(I2S_NUM_0);            
  Serial.println(">>> 雑音を完全シャットアウトしました。スピーカーは安全に静止しています。");

  Serial.println("🤖 起動セルフチェック開始：首と尻尾を動かします");

  // 1. 首を「右 ➔ 正面 ➔ 左 ➔ 正面」にシャキシャキ動かす
  servoPan.write(75);   delay(300);  // 右を向く
  servoPan.write(90);   delay(200);  // 正面に戻る
  servoPan.write(105);  delay(300);  // 左を向く
  servoPan.write(90);   delay(300);  // 正面に戻って静止

  // 2. 尻尾をお尻フリフリと「2回」振る
  for(int i = 0; i < 2; i++) {
    servoTail.write(120); delay(150);
    servoTail.write(60);  delay(150);
  }
  servoTail.write(90);  delay(100);
  
  Serial.println("🚀 オープニング演出完了！自律モードに移行します。");

  // WiFiを起動　WiFiのMACアドレスから下4桁を取得して固有デバイス名を生成
  WiFi.mode(WIFI_MODE_STA);
  // 無線チップが完全に目を覚ますまで、100ミリ秒（0.1秒）だけ待ちます
  delay(100); 
  // 準備が整ったので、安全に本物のMacアドレスを取得！
  String macStr = WiFi.macAddress();
  macStr.replace(":", "");
  // 下4桁を切り出してデバイス名にくっつける
  String macSuffix = macStr.substring(macStr.length() - 4);
  String deviceName = "iRobapp-mini-" + macSuffix;
  Serial.printf(">>> デバイス名を確定しました: %s\n", deviceName.c_str());

  BLEDevice::init(deviceName.c_str()); 
  pServer = BLEDevice::createServer();
  pServer->setCallbacks(new MyServerCallbacks());

  BLEService *pService = pServer->createService(SERVICE_UUID);
  BLEService *pBatteryService = pServer->createService(BATTERY_SERVICE_UUID);

  pEyeCharacteristic = pService->createCharacteristic(
    CHARACTERISTIC_EYE_UUID,
    BLECharacteristic::PROPERTY_WRITE
  );
  pEyeCharacteristic->setCallbacks(new EyeCallbacks());

  pVoiceCharacteristic = pService->createCharacteristic(
    CHARACTERISTIC_VOICE_UUID,
    BLECharacteristic::PROPERTY_WRITE    |
    BLECharacteristic::PROPERTY_WRITE_NR | 
    BLECharacteristic::PROPERTY_NOTIFY
  );
  pVoiceCharacteristic->setCallbacks(new VoiceCallbacks());

  pServoCharacteristic = pService->createCharacteristic(
    CHARACTERISTIC_SERVO_UUID,
    BLECharacteristic::PROPERTY_WRITE
  );
  pServoCharacteristic->setCallbacks(new ServoCallbacks());

  pVoiceCharacteristic->addDescriptor(new BLE2902());

  pService->start();

  // バッテリー残量特性（読み取り & 通知可能）の作成
  pBatteryCharacteristic = pBatteryService->createCharacteristic(
    BATTERY_CHARACTERISTIC_UUID,
    BLECharacteristic::PROPERTY_READ | BLECharacteristic::PROPERTY_NOTIFY
  );
  // デフォルト値をセット
  uint8_t initialLevel = getBatteryPercentage();
  pBatteryCharacteristic->setValue(&initialLevel, 1);

  // サービスを開始
  pBatteryService->start();


  BLEAdvertising *pAdvertising = BLEDevice::getAdvertising();
  pAdvertising->addServiceUUID(SERVICE_UUID);
  pAdvertising->addServiceUUID(BATTERY_SERVICE_UUID);
  pAdvertising->setScanResponse(true);
  BLEDevice::startAdvertising();
  
  Serial.println(">>> BLEアドバタイズ中...");
  lastBlinkTime = millis();
  lastInteractionTime = millis();
}

// -------------------------------------------------------------------------
// メインループ
// -------------------------------------------------------------------------
void loop() {
    // 4. 30秒ごとにバッテリー残量を更新してiPhoneに通知する
    if (millis() - lastBatteryUpdateTime > 30000) {
        lastBatteryUpdateTime = millis();
        
        uint8_t currentLevel = getBatteryPercentage();
        pBatteryCharacteristic->setValue(&currentLevel, 1);
        pBatteryCharacteristic->notify(); // iPhoneへ通知を送る
        
        Serial.printf("🔋 バッテリー残量を通知しました: %d%%\n", currentLevel);
    }

  if (!deviceConnected && oldDeviceConnected) {
      delay(500);
      pServer->startAdvertising();
      oldDeviceConnected = deviceConnected;
  }
  if (deviceConnected && !oldDeviceConnected) {
      oldDeviceConnected = deviceConnected;
  }

  // 🔊 音声の無通信タイムアウト判定（パケットが300ms途絶えたらアンプを安全に寝かせる）
  if (isAudioPlaying && (millis() - lastAudioPacketTime > 300)) {
    i2s_zero_dma_buffer(I2S_NUM_0);
    i2s_stop(I2S_NUM_0);
    isAudioPlaying = false;
    Serial.println(">>> 音声ストリーム終了。アンプを省電力停止しました。");
  }

  if (millis() - lastInteractionTime > SLEEP_TIMEOUT) {
    isSleepMode = true;
  }

  // おしゃべり受信時の尻尾フリフリ制御
  if (isTailWaggingForVoice) {
    unsigned long elapsed = millis() - tailMotionStartTime;
    if (elapsed < 135) {
      servoTail.write(120);
    } else if (elapsed < 270) {
      servoTail.write(60);
    } else if (elapsed < 405) {
      servoTail.write(120);
    } else if (elapsed < 540) {
      servoTail.write(60);
    } else {
      servoTail.write(90);
      isTailWaggingForVoice = false; 
    }
  } 
  else if (!isSleepMode && random(0, 1000) < 3) {
    moveHeadSmoothly(random(60, 120), headSpeed);

    if(random(0, 2) == 0) {
      servoTail.write(110); 
      delay(80);
      servoTail.write(70);  
      delay(80);
      servoTail.write(90);
    }
  }

  updateEyePhysics();
  drawEye();
  delay(16);
}

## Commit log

2026-08-22 Update 003_Body_Base_Case.py
    ・USB-Cアクセス窓（usb_hole）の追加
    XIAO ESP32-S3にいつでもPCからプログラムを書き込んだり、充電・給電ができるよう、背面の左寄りの位置に幅11.0mm × 高さ6.5mmの四角い貫通窓を開けました。これにより、外からType-Cケーブルのプラグを奥までしっかり挿し込めます。
    ・変数名の完全同期
    001や002と合わせ、サーボのネジピッチを保持する変数名を servo_pitch から head_screw_pitch に変更しました。プロジェクト全体で共通のパラメータ形式になったため、可読性が大幅に向上しています
2026-08-22 Update 002_Neck_Joint_Mount.py
    サーボホーン固定用のネジ穴を追加
2026-08-22 Update 002_Neck_Joint_Mount.md
    コの字型に変更
2026-08-23 feat:設定変更
2026-08-23 Update 開発者の方へ.md
    feat:世界標準の「Conventional Commits」ルールを追記しました。
2026-08-23 Update 開発者の方へ.md
    feat:Gemma 2B モデルファイルのダウンロード ＆ 配置手順追加
2026-08-23 Update 開発者の方へ.md
    feat:Kaggleの無料アカウント登録が必要なことを追記
2026-08-23 Update 開発者の方へ.md
    feat:Kaggleについてコメントを追記
2026-08-23 Update 開発者の方へ.md
    feat:ダウンロード手順を修正。
2026-08-23 Update 開発者の方へ.md
    feat:ダウンロード方法を変更
2026-08-23 feat: ローカルAI(Gemma 2B)と設定画面の統合
2026-08-23 Update README.md
    feat:iOSAppの追加
2026-08-24 Update パーツ寸法表.md
    feat:配置する部品コードを明記しました。
2026-08-24 Update パーツ寸法表.md
    feat:I2Sオーディオアンプを追記
2026-08-24 Update 004_Bottom_Lid_Battery_Holder.py
    feat:スライドスイッチ用の穴とヒューズ用ボックスを追加。
2026-08-24 Update 003_Body_Base_Case.py
    feat:アンプ用リブ追加
2026-08-24 Update 003_Body_Base_Case.py
    feat:スピーカー用フォルダ削除、アンプ用は残す。
2026-08-24 Update 001_Head_Face_Connector.py
    feat:アンプ用リブとスピーカー用リブ追加。
2026-08-24 Update 001_Head_Face_Connector.py
    feat:Waveshare19192突起対応
2026-08-24 Update パーツ寸法表.md
    feat:アンプとスピーカーを頭部に移動
2026-08-25 Create development-log.md doc:開発日記新規作成
2026-08-25 Update 001_Head_Face_Connector.md doc:アンプとスピーカーをこちらに移動にしたことによる修正。
2026-08-25 docs: 回路図の追加
2026-08-25 docs: 全ドキュメントの液晶表記をWAVESHARE 19192に完全統一
    grep検索で抽出した4ファイル（仕様書、手順書、CAD解説、配線表）のGC9A01表記を、実物の製品名であるWAVESHARE 1.28inch LCD Module (19192)に統一。プロジェクト全体の整合性を向上。
2026-08-25 Update development-log.md doc:2026/08/25(火)作業分追記
2026-08-25 feat: 初の実機動作成功！丸型液晶へLovyanGFXによる瞳アニメーションの描画実装
    4日目の最終目標を達成。XIAO ESP32-S3へ下駄をハンダ付けし、WAVESHARE 19192(GC9A01)との物理配線を完了。D5〜D10の最新ピンアサインにて、チラつきのない滑らかな目玉のキョロキョロ・瞬き動作が100%正常に起動することを確認。
2026-08-25 feat: 音声再生確認＆サーボ動作確認
2026-08-26 feat: おしゃべり機能のベース開通,ストリーミング再生にてスピーカーからの音を確認（雑音がひどい）
2026-08-26 feat: 目を１つから２つに変更
2026-08-27 doc: en配線追加
2026-08-27 Update development-log.md doc:2026/08/27作業分
2026-08-27 feat: 設定画面の拡張＆TTSて入力テキストの追加
2026-08-29 feat: Gemma 2B ローカルAIの実装
2026-08-29 feat: AVAudioSession の設定を修正
2026-08-29 feat: バッファ取得が完了する前に送信処理が走ってる
2026-08-30 feat: 音量・音質調整
2026-08-30 feat: STL出力
    [iRobapp_mini_Body_Base1-Body_Base_Case.stl, iRobapp_mini_Bottom_Lid1-Bottom_Lid_Battery_Holder.stl, iRobapp_mini_Head_Case-Head_Face_Connector.stl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]
2026-08-31 feat: AI調整
2026-09-01 feat: AI周りの強化
2026-09-01 feat: バッテリーモニター追加
2026-09-01 feat: バッテリーモニター修正
2026-09-01 feat: 音声周りの修正
2026-09-03 CAD修正
    [iRobapp_mini_Body_Base1-Body_Base_Case.stl, iRobapp_mini_Bottom_Lid1-Bottom_Lid_Battery_Holder.stl, iRobapp_mini_Neck_Joint1-Neck_Joint_Mount.3mf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]
2026-09-03 接続図を修正
2026-09-04 Update wiring table for power connections
2026-09-04 feat: CAD修正
    [iRobapp_mini_Neck_Joint1-Neck_Joint_Mount.stl]
2026-09-04 feat: サーボコマンド実装
2026-09-05 feat: サーボコマンド修正
2026-09-05 feat:アジャスター追加
    [iRobapp_mini_20mm_Adjuster-iRobapp_mini_20mm_Adjuster.stl]
